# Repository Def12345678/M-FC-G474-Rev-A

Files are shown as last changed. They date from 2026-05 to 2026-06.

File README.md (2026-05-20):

# M-FC — Modular Flight Controller (REV-1)

> **Note:** This is REV-1 — a Proof-of-Concept / educational build. REV-2 is in development and will address known hardware ergonomics issues. Not recommended for production use.

M-FC has been flying on a 5" freestyle build for over a year.

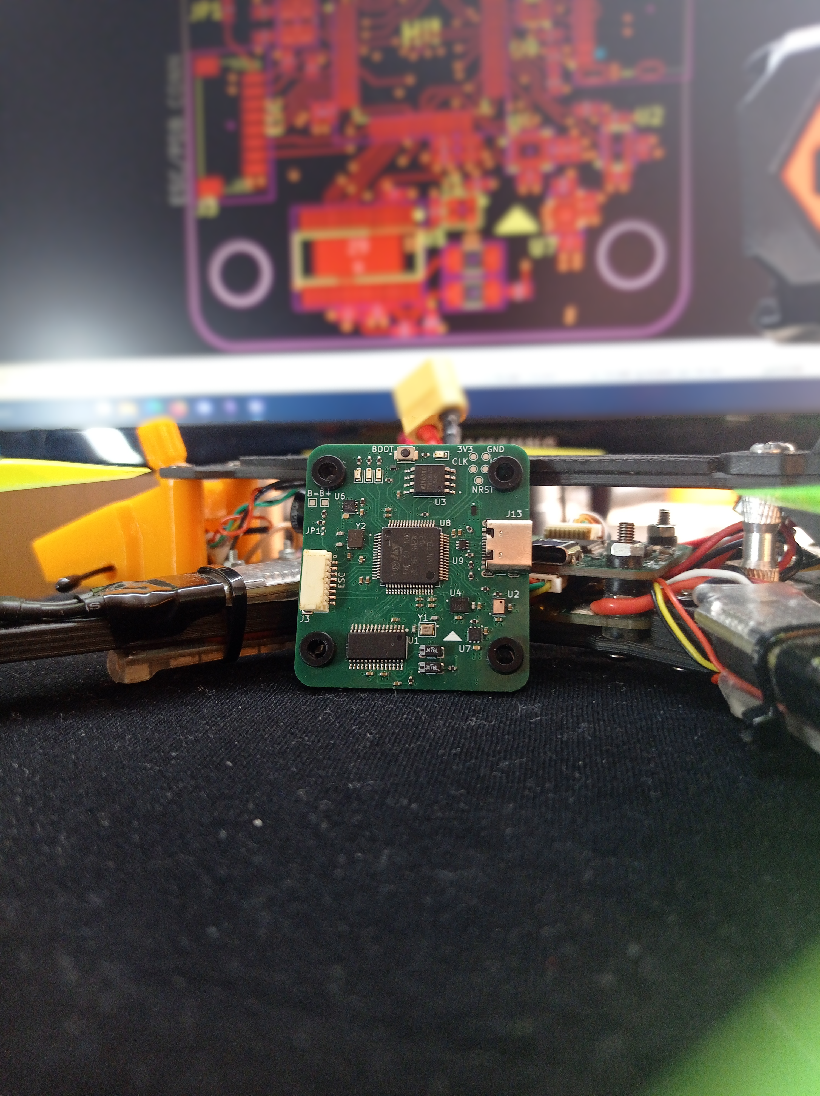
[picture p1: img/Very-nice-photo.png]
M-FC + M-PDB stack installed in Geprc MK4 5" frame


---

## Overview

M-FC is a DIY flight controller designed for FPV drones 30.5x30.5mm mounting holes, built around the STM32G474RET6 microcontroller and running Betaflight 4.6. The "Modular" name reflects the connector philosophy — every peripheral interface is broken out via JST-SH connectors, making wiring clean, repeatable, and swap-friendly.

The board is paired with a dedicated PDB in a standard FC/PDB stack configuration. The FC itself operates at 5V (no onboard BEC), sourcing power from the ESC or PDB. REV-2 will include an onboard BEC.

---

## Hardware Specifications

| Component | Details |
|---|---|
| **MCU** | STM32G474RET6 |
| **IMU** | ICM-42688-P (SPI2) |
| **Barometer** | DPS368 (I2C4) |
| **Magnetometer** | Not populated |
| **OSD** | AT7456E (SPI1) |
| **Blackbox Flash** | W25Q128JVSIQ — 16 MB (SPI3) |
| **USB** | USB-C (with detect on PA10) |
| **Mounting** | 30.5 × 30.5 mm |
| **Input Voltage** | 5V (no onboard BEC — requires 5V from ESC or PDB) |

### Power Architecture

The FC does not regulate voltage from the battery. **5V must be supplied externally** — either from an ESC BEC or from the PDB — via the dedicated 5V pads on the board.

Two separate LDO regulators are present onboard:
- One for the MCU
- One for sensors (IMU, barometer)

A **Schottky diode** is used to isolate USB power from battery power. When powered via USB only, the FC supplies power exclusively to the MCU, sensors (IMU, barometer), OSD chip, flash, GPS, and RX. All remaining peripherals (motors, VTX, etc.) are only powered when the battery is connected via the PDB.

### PDB (Stack)

| Parameter | Value |
|---|---|
| **Max continuous current** | ~120 A total |
| **Per-motor channel** | ~30 A |
| **Configuration** | FC + PDB stack |

The FC connects to the PDB via an 8-pin JST-SH connector plus dedicated `5V_IN` and `GND` solder pads. The `5V_IN` pad powers the FC only — it does not back-feed to the PDB rail.

The PDB includes:
- **5V buck converter** — 2.5 A output
- **9V buck converter** — 2.5 A output (configurable to 12V by replacing resistor R5 — refer to the schematic for the correct resistor value via the linked Texas Instruments buck calculator)

Each ESC must be connected through the PDB. The `VBAT` pin on the 8-pin JST-SH outputs a voltage-divided signal safe for the MCU ADC, used for battery voltage monitoring in Betaflight.

---

## Connector Pinout

All peripheral connections use JST-SH connectors.

| Connector | Pins | Interface | Notes |
|---|---|---|---|
| **ESC** | 8 | DSHOT + telemetry | Motors 1–4 |
| **RX** | 4 | UART | RC receiver |
| **CAM** | 3 | Camera control | Analog camera |
| **VTX** | 4 | UART | Video transmitter |
| **GPS** | 6 | UART + I2C | GPS + compass |
| **LED** | 3 | LED strip | Addressable LEDs |

### Additional Exposed Pads

- **5V input pads** — mandatory external 5V supply
- **PWM 1–3** — additional PWM outputs
- **UART breakout** — spare UART pads
- **I2C breakout** — spare I2C pads

### Photos & Pinout Diagrams

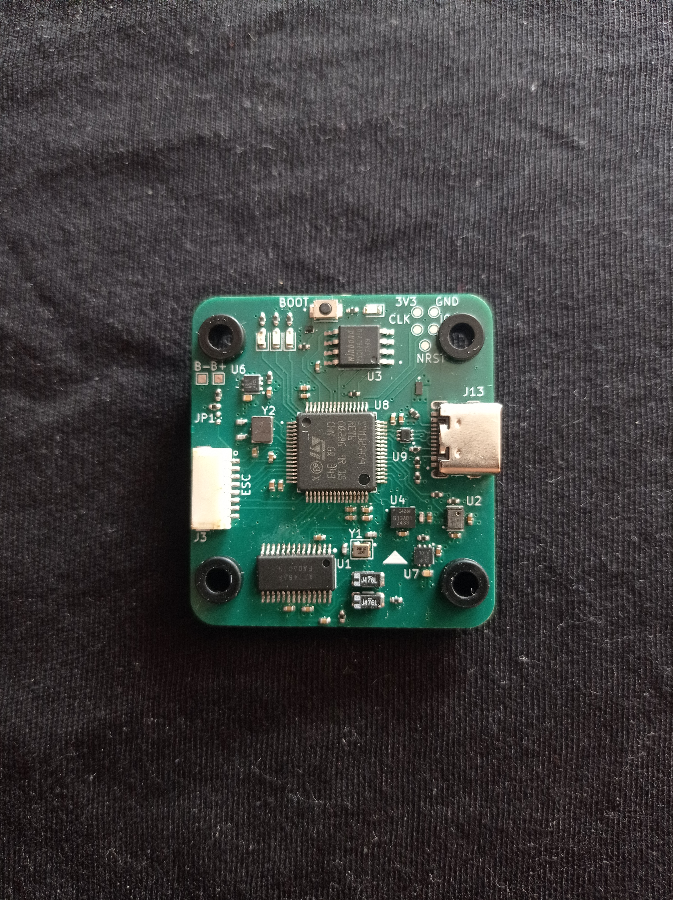
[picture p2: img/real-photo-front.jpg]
M-FC REV-1 — assembled board


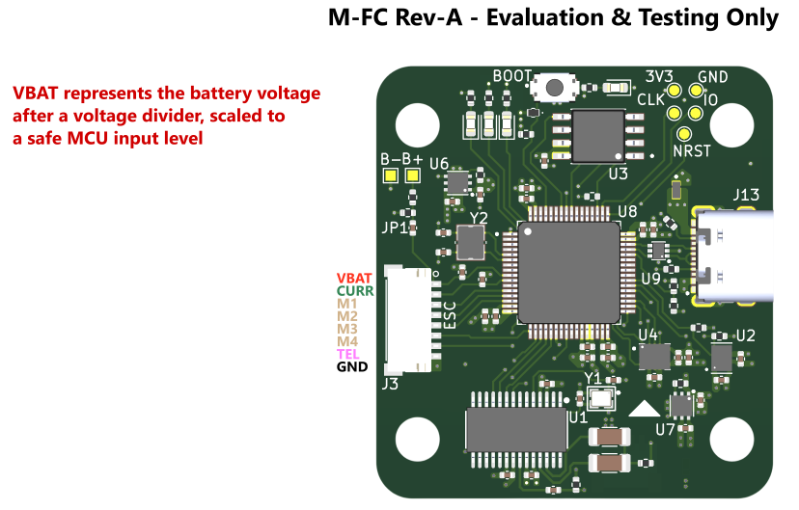
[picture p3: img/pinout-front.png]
Connector pinout — front


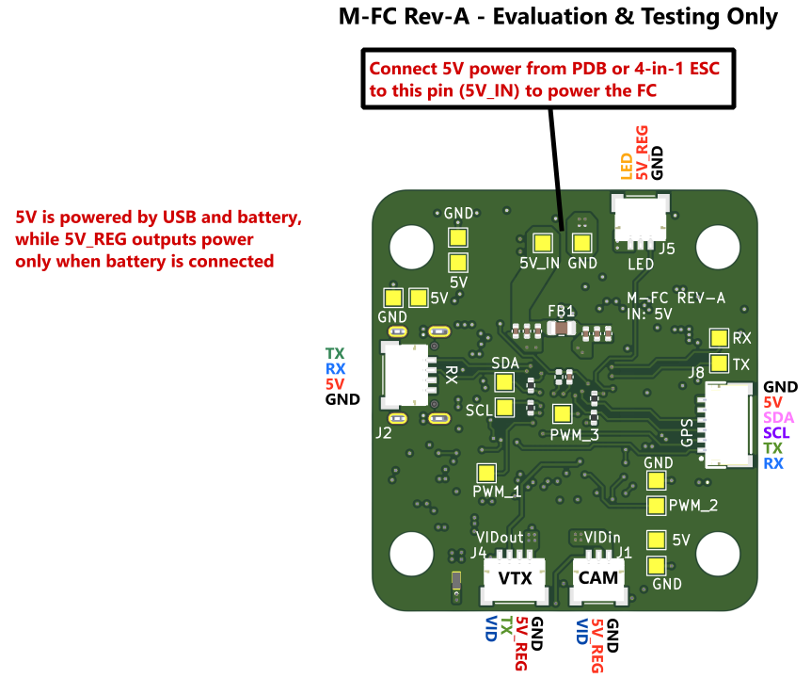
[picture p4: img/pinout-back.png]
Connector pinout — back


Additional renders, routing views, and PCB previews are available in the [`img/`](img/) folder.

---

## Betaflight Target

- **Betaflight version:** 4.6
- **Target name:** `M-FC`
- **MCU family:** `STM32G47X`

Pre-compiled firmware (`.hex`) and the target config file are included in this repository. The hex supports all features listed below.

### Enabled Features

| Feature | Detail |
|---|---|
| Gyroscope / Accelerometer | ICM-42688-P via SPI2 |
| Barometer | DPS368 via I2C4 |
| Blackbox | W25Q128FV via SPI3, default device |
| OSD | MAX7456 (AT7456E) via SPI1 |
| Motors | DSHOT bitbang, pins PA0–PA3 |
| LED strip | PC0 |
| Buzzer | PC3 (inverted) |
| Debug LEDs | PB6, PB7, PB9 |
| VBAT ADC | PC1 |
| Current ADC | PC2 |
| Camera control | PB0 |
| GPS | Enabled |
| Magnetometer | Enabled (I2C2) |
| Position hold | Enabled |
| Altitude hold | Enabled |

### UART Map

| UART | TX | RX | Suggested Use |
|---|---|---|---|
| UART1 | PC4 | PC5 | — |
| UART3 | PB10 | PB11 | — |
| UART4 | PC10 | PC11 | — |
| UART5 | PC12 | PD2 | — |

### I2C Map

| Bus | SCL | SDA | Used for |
|---|---|---|---|
| I2C2 | PA8 | PA9 | Magnetometer |
| I2C3 | PC8 | PC9 | — |
| I2C4 | PC6 | PC7 | Barometer (DPS368) |

### Motor Timer Map

| Index | Pin | Timer | Channel |
|---|---|---|---|
| Motor 1 | PA0 | TIM2 | CH1 |
| Motor 2 | PA1 | TIM2 | CH2 |
| Motor 3 | PA2 | TIM2 | CH3 |
| Motor 4 | PA3 | TIM2 | CH4 |
| CC | PB0 | TIM3 | CH3 |
| LED strip | PC0 | — | CH1 |

---

## Flashing Firmware

### Pre-compiled hex

1. Download the `.hex` file from this repository.
2. Open **Betaflight Configurator 10.10+**.
3. Enter DFU mode — hold the boot button while plugging in USB-C, or send `bl` via CLI.
4. In the **Firmware Flasher** tab, select **Load Firmware [Local]** and pick the `.hex`.
5. Flash. Avoid **Full chip erase** unless necessary.

### Building from source

You can compile your own firmware with custom flags. Copy the target config file into the `configs/` folder of the Betaflight source tree, then build normally.

Building was tested using WSL. Refer to the official Betaflight build guide for setup instructions:
[https://betaflight.com/docs/development/building/Building-in-Ubuntu](https://betaflight.com/docs/development/building/Building-in-Ubuntu)

## Flight Logs & Blackbox Data

Blackbox logs and DVR footage from test flights are available in the [`logs/`](logs/) folder and on https://youtu.be/7Q5jRaf4V_Y(#) / https://pixeldrain.com/u/gxZJVt8E(#).

Logs were recorded using the onboard W25Q128JVSIQ flash via Betaflight 4.6 blackbox at 1kHz.

## Test build
| Component | Details |
|---|---|
| **ESC** | LittleBee Spring 30A (BlueJay firmware) |
| **VTX** | SpeedyBee TX800 (Pagoda2) |
| **RX** | SpeedyBee Nano ELRS |
| **Camera** | Mista 1672 |
| **Motors** | Emax RS2205 2350KV |
| **Battery** | 4S 1550mAh (Ovionic) |
| **Frame** | Geprc MK4 5" |

---

## Known Issues (REV-1)

- **Connector placement ergonomics** — JST-SH connectors are not optimally positioned for clean cable routing in a standard stack build. This is the primary driver for REV-2.
- **Betaflight 4.5 blackbox bug** — Blackbox was unreliable on Betaflight 4.5. Betaflight 4.6 resolves this; use 4.6 or later.
- **No onboard 5V BEC** — Requires external 5V source from ESC or PDB.

---

## Planned Changes (REV-2)

- Revised connector layout for improved cable management
- Onboard 5V BEC
- Additional ergonomic improvements based on REV-1 testing

---

## Acknowledgements

Thanks to [@awocrf](https://github.com/awocrf) for reviewing the schematic for correctness and readability, and for helping with PCB layout aesthetics.

---

## License

This project is released under the **MIT License**. See [LICENSE](LICENSE) for details.

Firmware is based on [Betaflight](https://github.com/betaflight/betaflight), licensed under **GPLv3**.

---

## Contributing

This is currently a personal/educational project. REV-2 is in active development. Issues and suggestions are welcome via GitHub Issues.

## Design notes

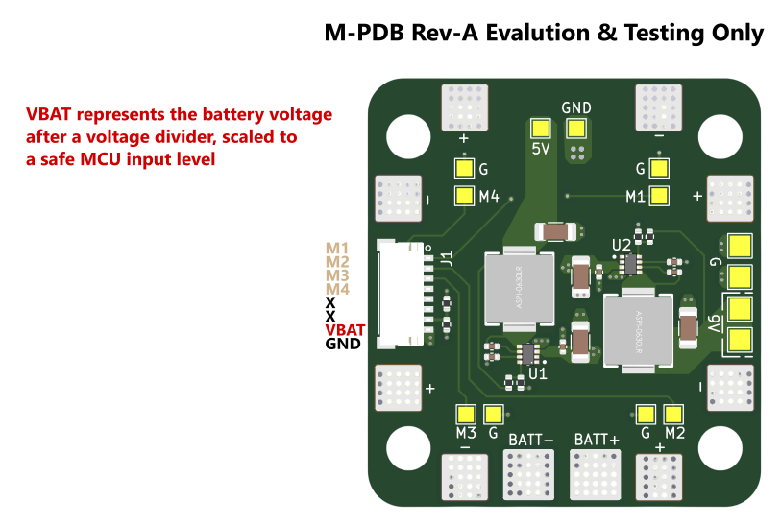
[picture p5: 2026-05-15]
img/M-PDB-img/pinout-M-PDB.png

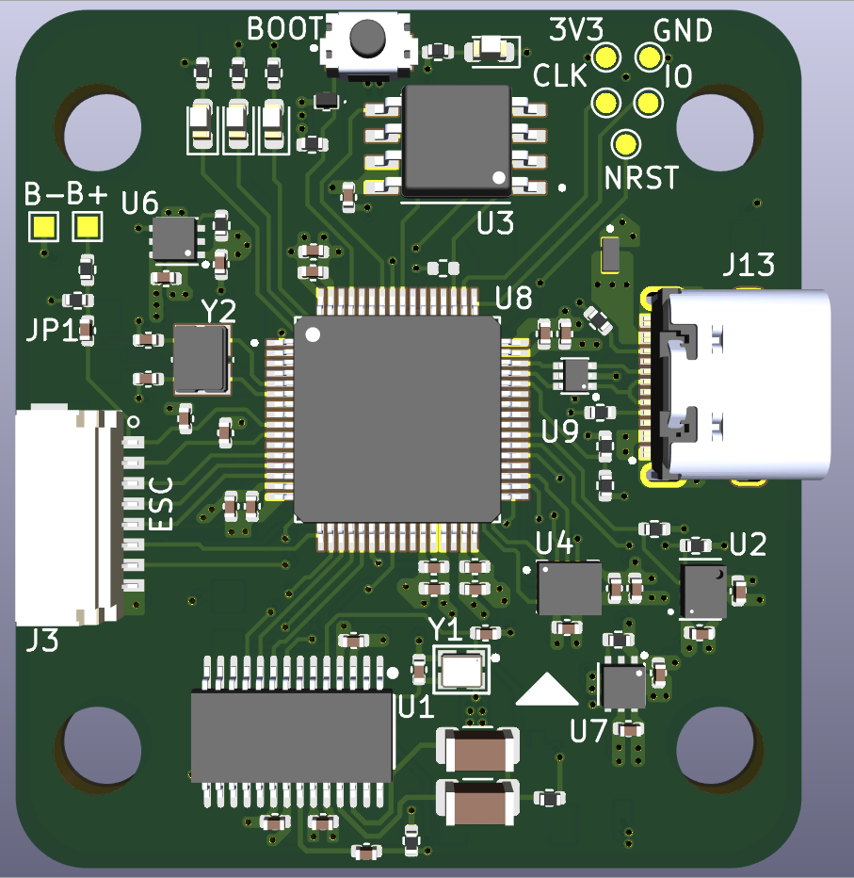
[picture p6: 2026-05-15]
img/render-front.png

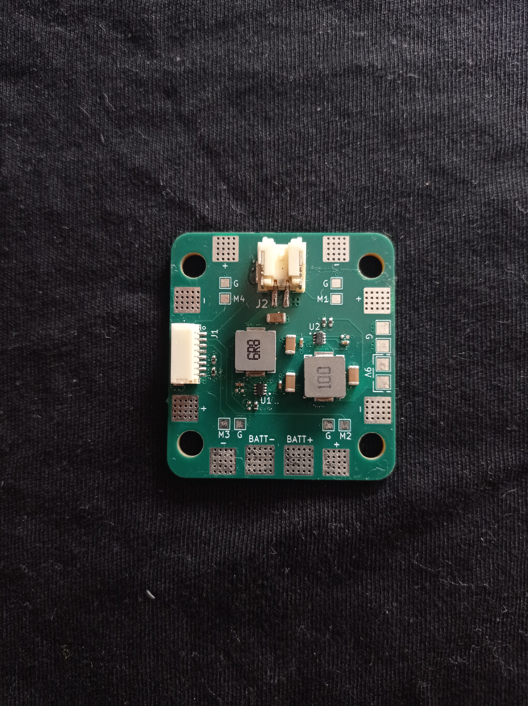
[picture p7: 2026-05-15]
img/M-PDB-img/real-photo-M-PDB.jpg

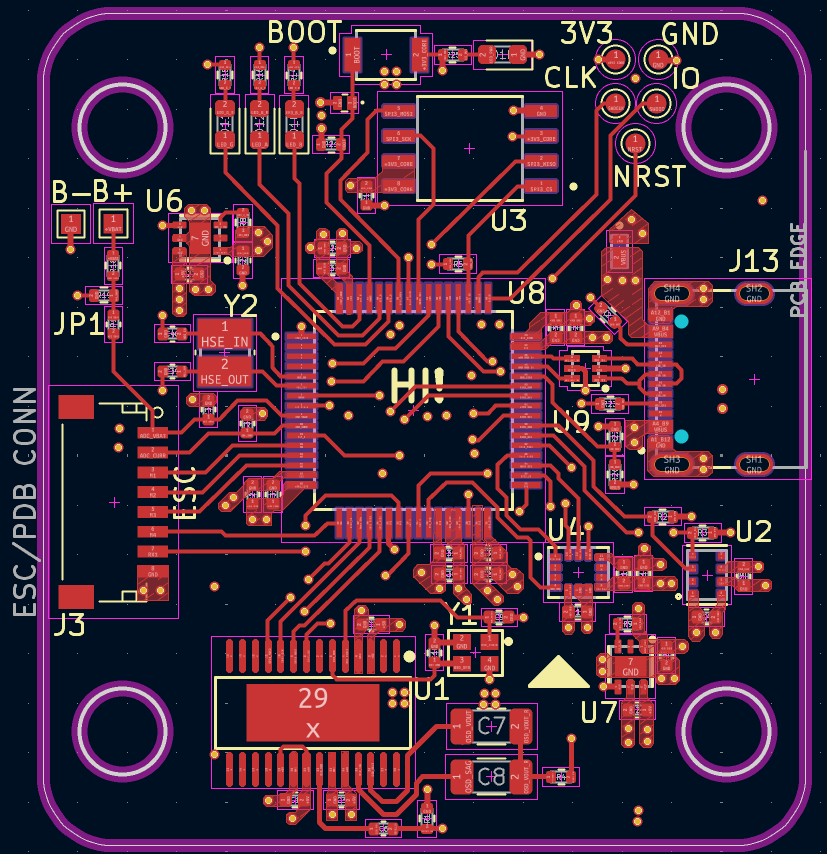
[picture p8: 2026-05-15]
img/routing-first-layer.png

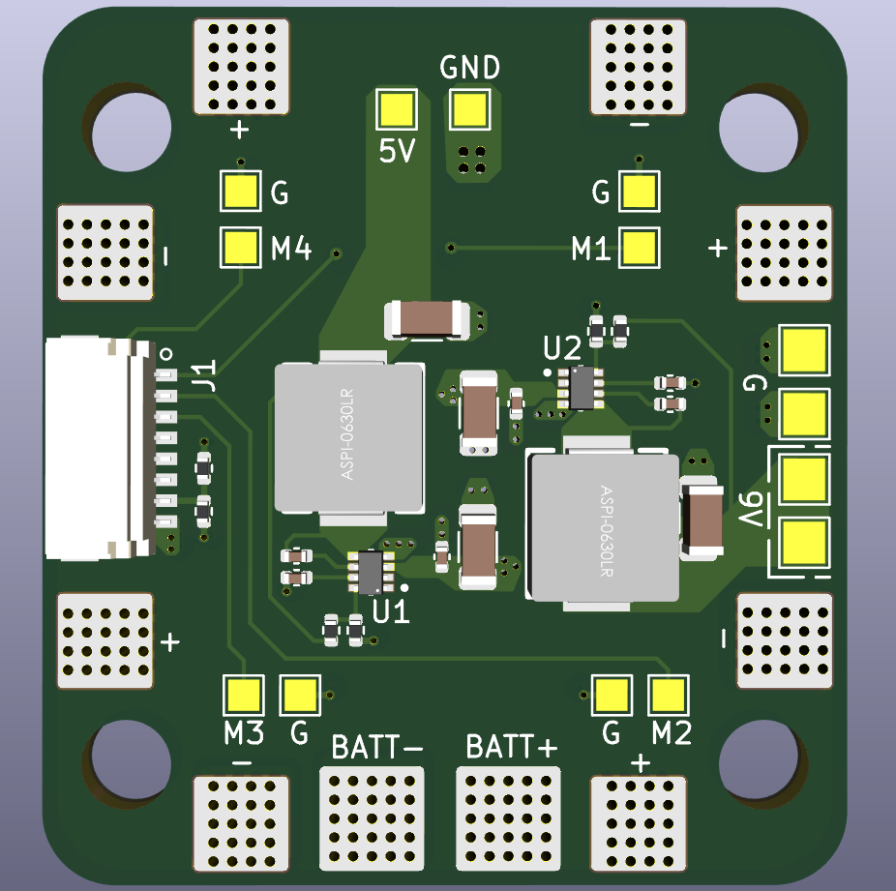
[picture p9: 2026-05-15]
img/M-PDB-img/render-M-PDB.png

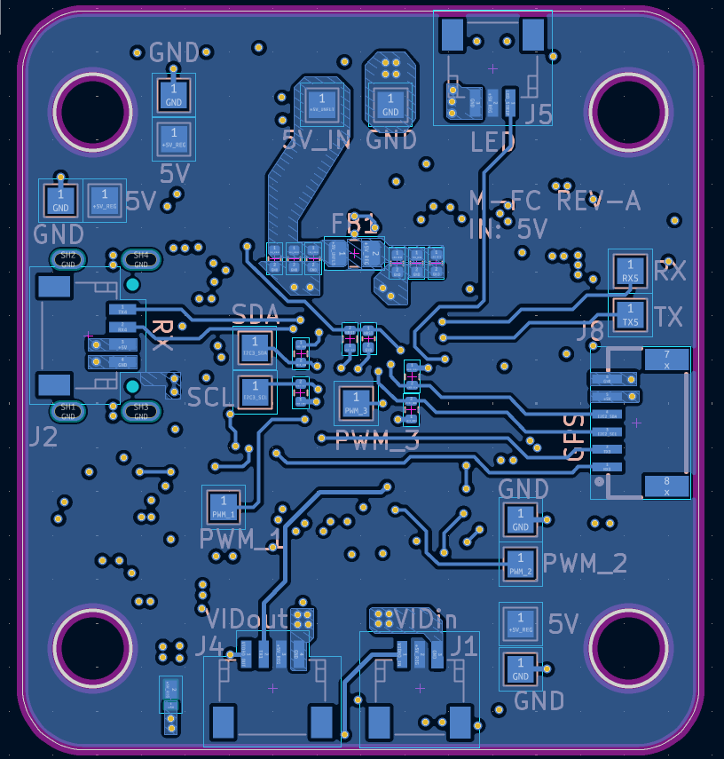
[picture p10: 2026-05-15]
img/routing-fourth-layer.png

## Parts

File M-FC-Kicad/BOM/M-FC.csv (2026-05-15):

Id | Designator | Footprint | Quantity | Designation | Supplier and ref
1 | J3 | JST_SH_SM08B-SRSS-TB_08x1.00mm_Angled | 1 | ESC/PDB CONN
2 | C29,C27,C26,C28,C25,C23 | C_0402_1005Metric | 6 | 1u
3 | C9,C10,C39,C40 | C_0402_1005Metric | 4 | 10p
4 | U7,U6 | SON65P200X200X80-7N | 2 | LP5912-3.3DRV
5 | D18 | LED_0603_1608Metric | 1 | RED
6 | C14,C42,C41 | C_0402_1005Metric | 3 | 10n
7 | C13,C33,C6,C5,C4,C35,C11,C31,C32,C34,C3,C2,C1,C38,C37,C30,C20,C43,C36 | C_0402_1005Metric | 19 | 100n
8 | R16,R15,R25,R14 | R_0402_1005Metric | 4 | 1K
9 | Y1 | CRYSTAL-SMD_4P-L2.0-W1.6-BL | 1 | 27MHz
10 | U2 | XDCR_DPS368XTSA1 | 1 | DPS368XTSA1
11 | U9 | SOT50P160X60-6N | 1 | USBLC6-2P6
12 | R4,R1 | R_0402_1005Metric | 2 | 75
13 | C24,C22,C19,C44 | C_0402_1005Metric | 4 | 10u
14 | R3,R21,R2,R9,R8,R11,R13,R10,R12 | R_0402_1005Metric | 9 | 10k
15 | D10 | LED_0603_1608Metric | 1 | Blue
16 | D11 | LED_0603_1608Metric | 1 | Green
17 | U1 | TSSOP-28_L9.7-W4.4-P0.65-LS6.4-BL-EP-2 | 1 | AT7456E
18 | U3 | SOIC127P790X216-8N | 1 | W25Q128JVSIQ
19 | C12 | C_0402_1005Metric | 1 | 2p2
20 | D2,D1 | DIO_SDM2U40CSP-7B | 2 | SDM2U30CSP-7B
21 | R18,R22,R20 | R_0402_1005Metric | 3 | 100K
22 | R23,R24 | R_0402_1005Metric | 2 | 5K1
23 | C8,C7 | C_1206_3216Metric | 2 | 47u
24 | Y2 | XTAL_NX3225GD-8MHZ-STD-CRA-3 | 1 | 8MHz
25 | R5,R19,R17 | R_0402_1005Metric | 3 | 10K
26 | U8 | QFP50P1200X1200X160-64N | 1 | STM32G474RET6
27 | D14 | ESDALC6V1-1U2 | 1 | ESD
28 | SW1 | SW_B3U-1000P | 1 | BOOT0
29 | D12 | LED_0603_1608Metric | 1 | Amber
30 | U4 | PQFN50P300X250X97-14N | 1 | ICM-42688-P
31 | J13 | KINGHELM_KH-TYPE-C-16P | 1 | USB-C-16P
32 | J4 | JST_SH_SM04B-SRSS-TB_04x1.00mm_Angled | 1 | VTX
33 | J8 | CONN-SMD_6P-P1.00_XUNPU_WAFER-SH1.0-6PWB | 1 | GPS
34 | J1 | JST_SH_SM03B-SRSS-TB_03x1.00mm_Angled | 1 | CAM
35 | FB1 | C_0805_2012Metric | 1 | 300R
36 | J5 | JST_SH_SM03B-SRSS-TB_03x1.00mm_Angled | 1 | LED
37 | J2 | JST_SH_SM04B-SRSS-TB_04x1.00mm_Angled | 1 | RX

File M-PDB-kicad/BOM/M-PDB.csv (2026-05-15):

Id | Designator | Footprint | Quantity | Designation | Supplier and ref
1 | C2,C9,C7,C4 | C_1206_3216Metric | 4 | 10u
2 | L1 | IND-SMD_L7.0-W6.6 | 1 | 6u8
3 | C8,C3,C1,C6 | C_0402_1005Metric | 4 | 100n
4 | J1 | JST_SH_SM08B-SRSS-TB_08x1.00mm_Angled | 1 | FC Conn
5 | C10,C5 | C_0402_1005Metric | 2 | 33n
6 | R5 | R_0402_1005Metric | 1 | 102K
7 | U2,U1 | SOTFL50P160X60-8N | 2 | TPS62933DRLR
8 | L2 | IND-SMD_L7.0-W6.6 | 1 | 10u
9 | R3,R4,R6 | R_0402_1005Metric | 3 | 10K
10 | R1 | R_0402_1005Metric | 1 | 100K
11 | R2 | R_0402_1005Metric | 1 | 52K3

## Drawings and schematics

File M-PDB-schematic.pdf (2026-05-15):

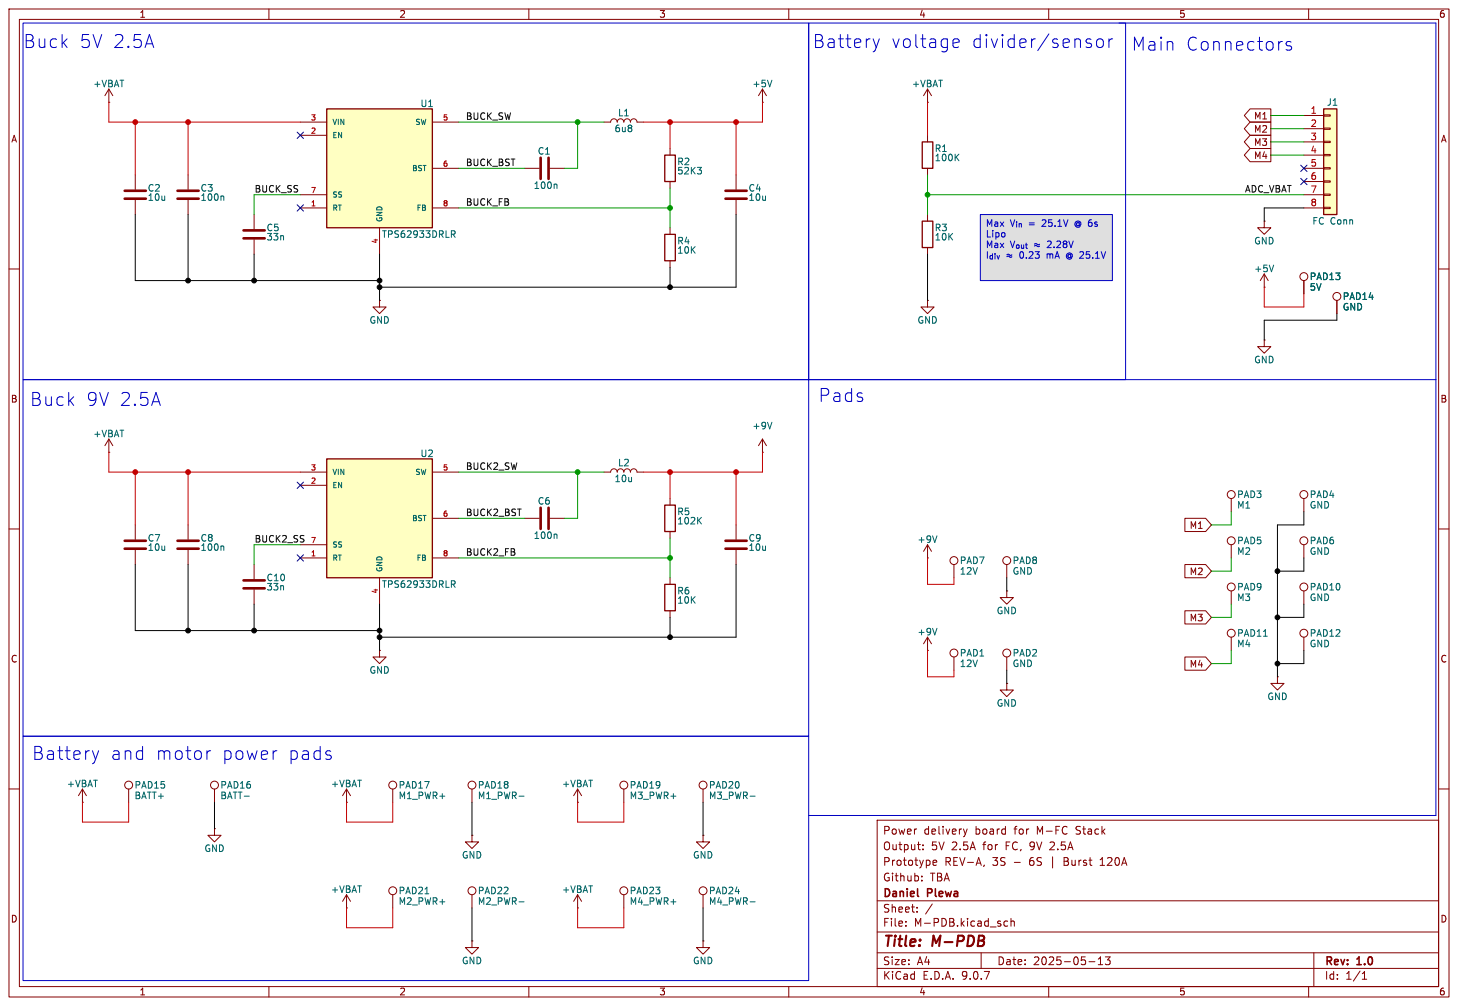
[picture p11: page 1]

Max V_{in}= 25.1V @ 6s Lipo Max V_{out}þÿ"H2.28V

4 SW 5 BST 6 FB 8 U2 TPS62933DRLR GND

Battery and motor power pads

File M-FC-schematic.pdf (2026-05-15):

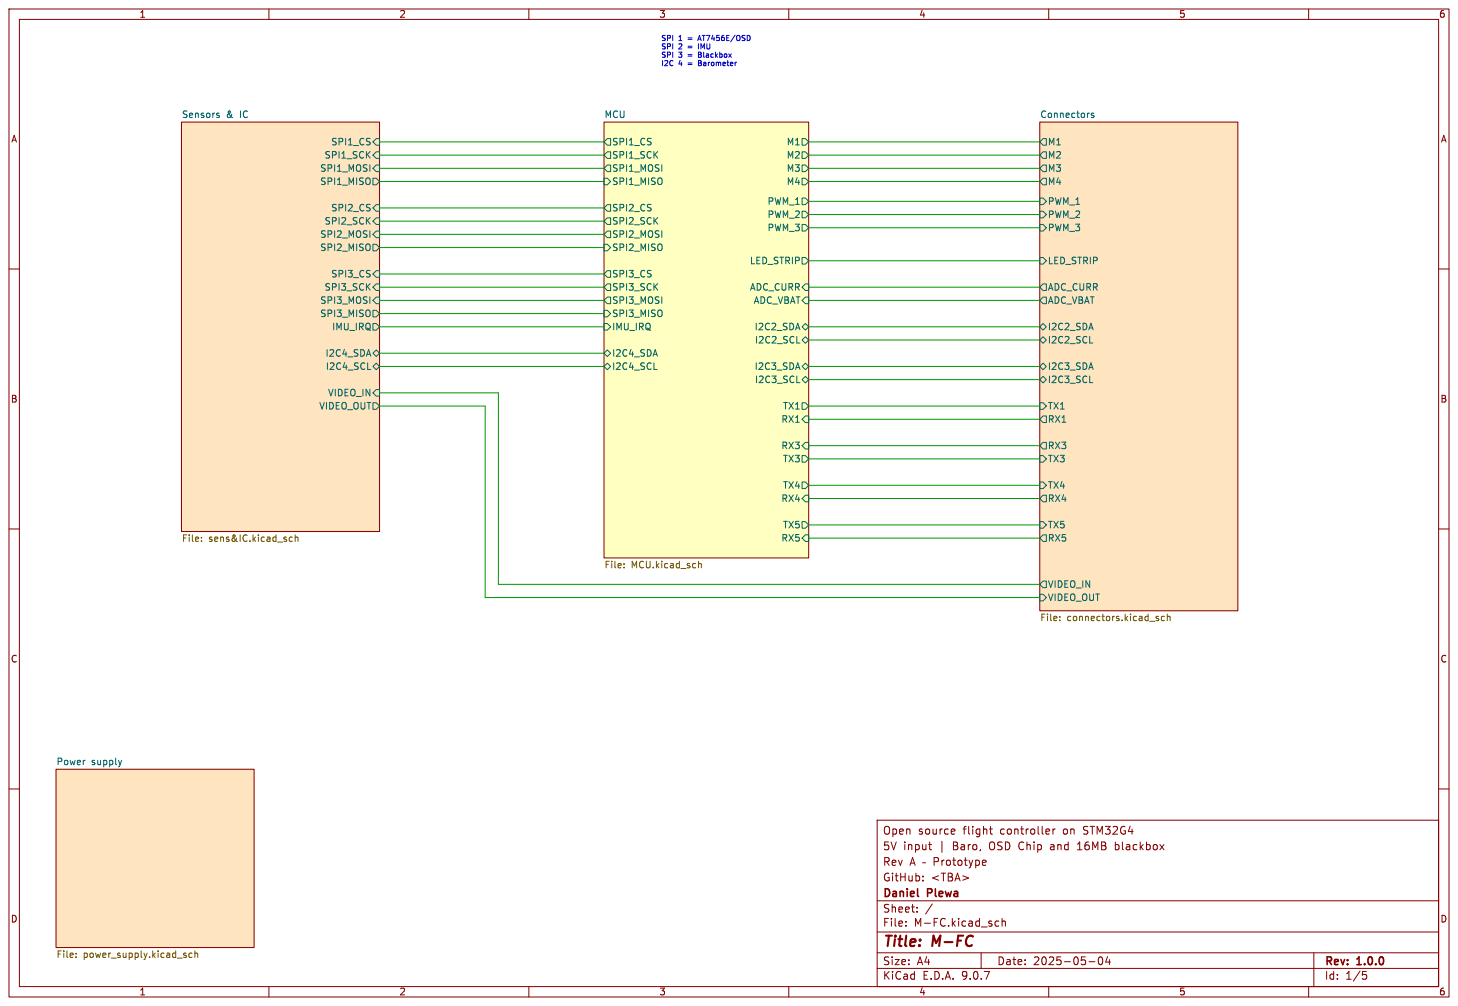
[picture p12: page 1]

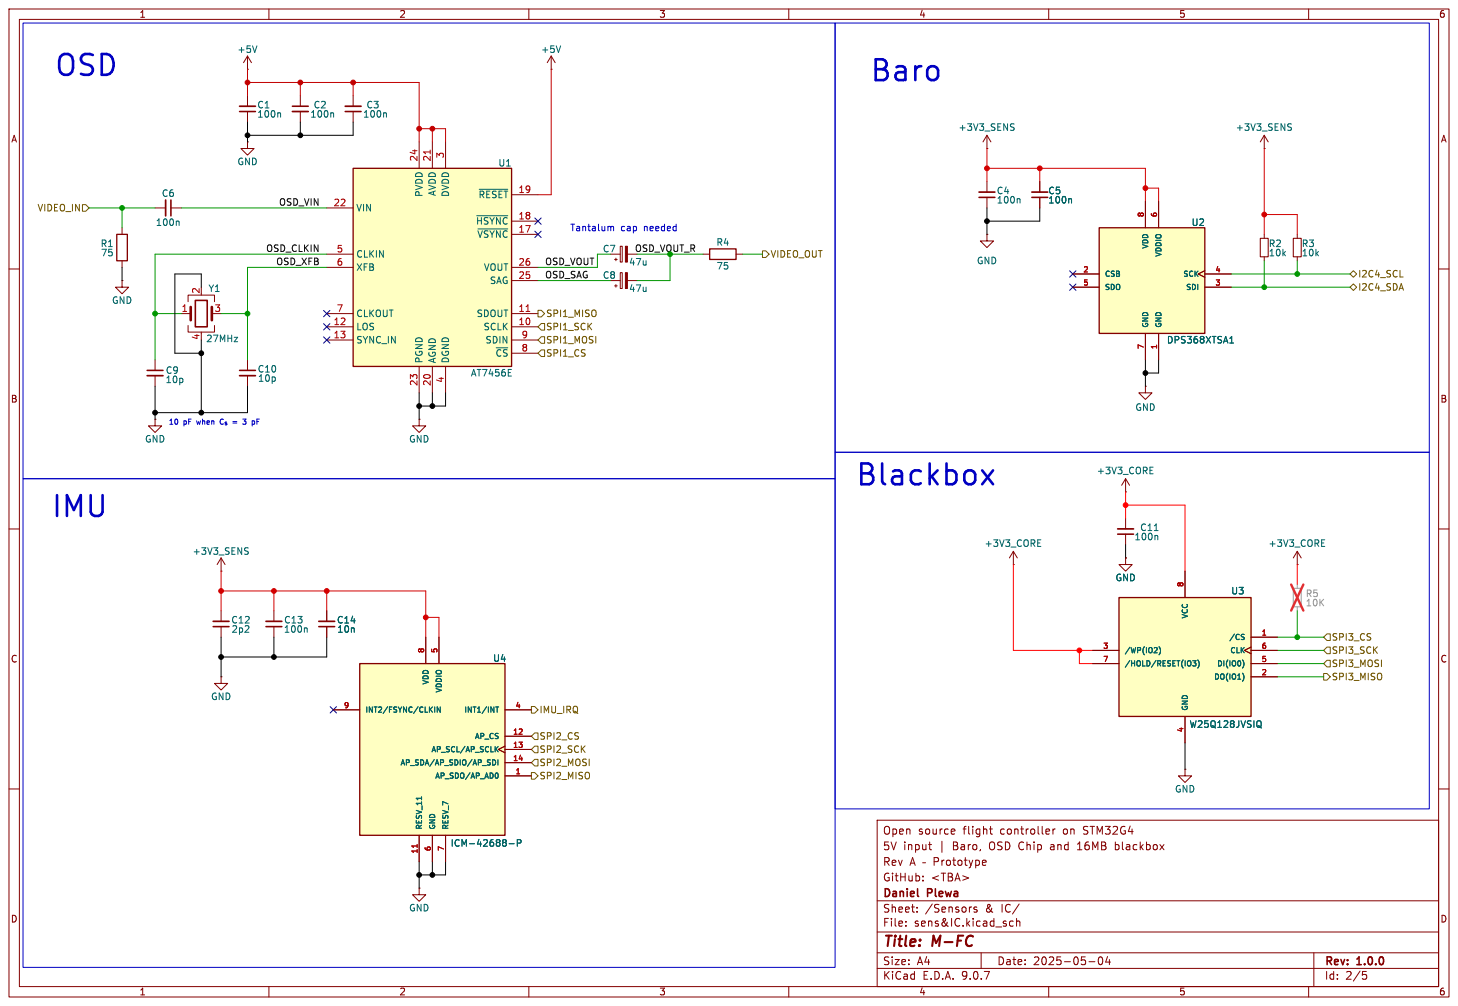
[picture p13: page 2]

4 ~{RESET}19 ~{HSYNC}18 ~{VSYNC}17 VOUT 26 SAG 25 SDOUT 11 SCLK 10 SDIN 9 ~{CS} 8 U1 AT7456E GND

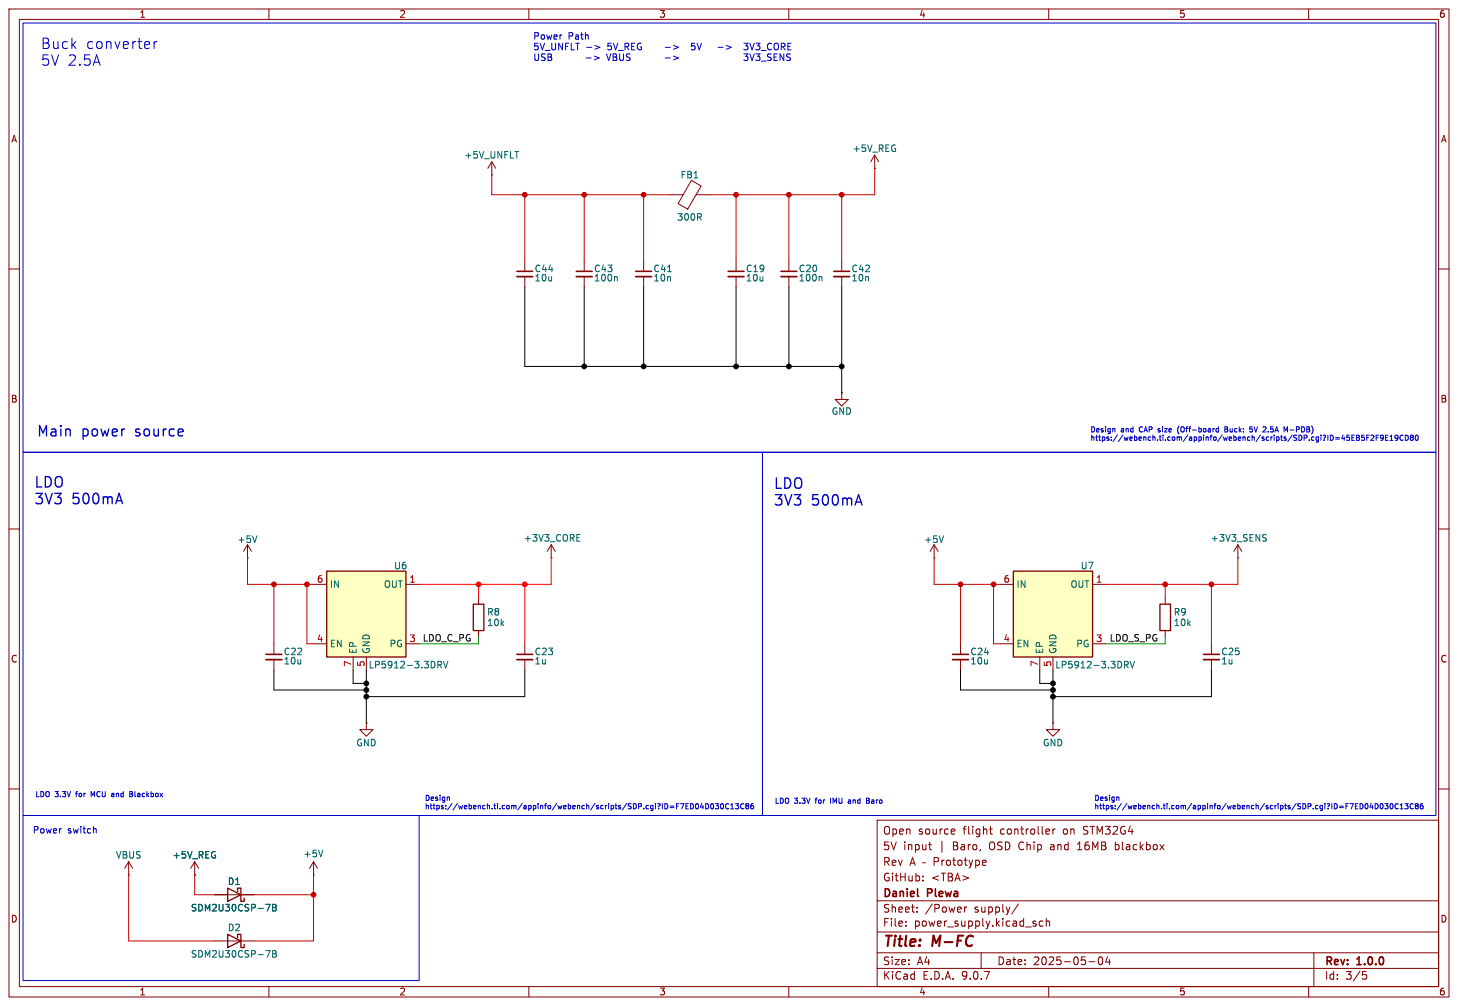
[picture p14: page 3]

LDO 3.3V for MCU and Blackbox Main power source

LDO 3.3V for IMU and Baro LDO

https://webench.ti.com/appinfo/webench/scripts/SDP.cgi?ID=F7ED04D030C13C86

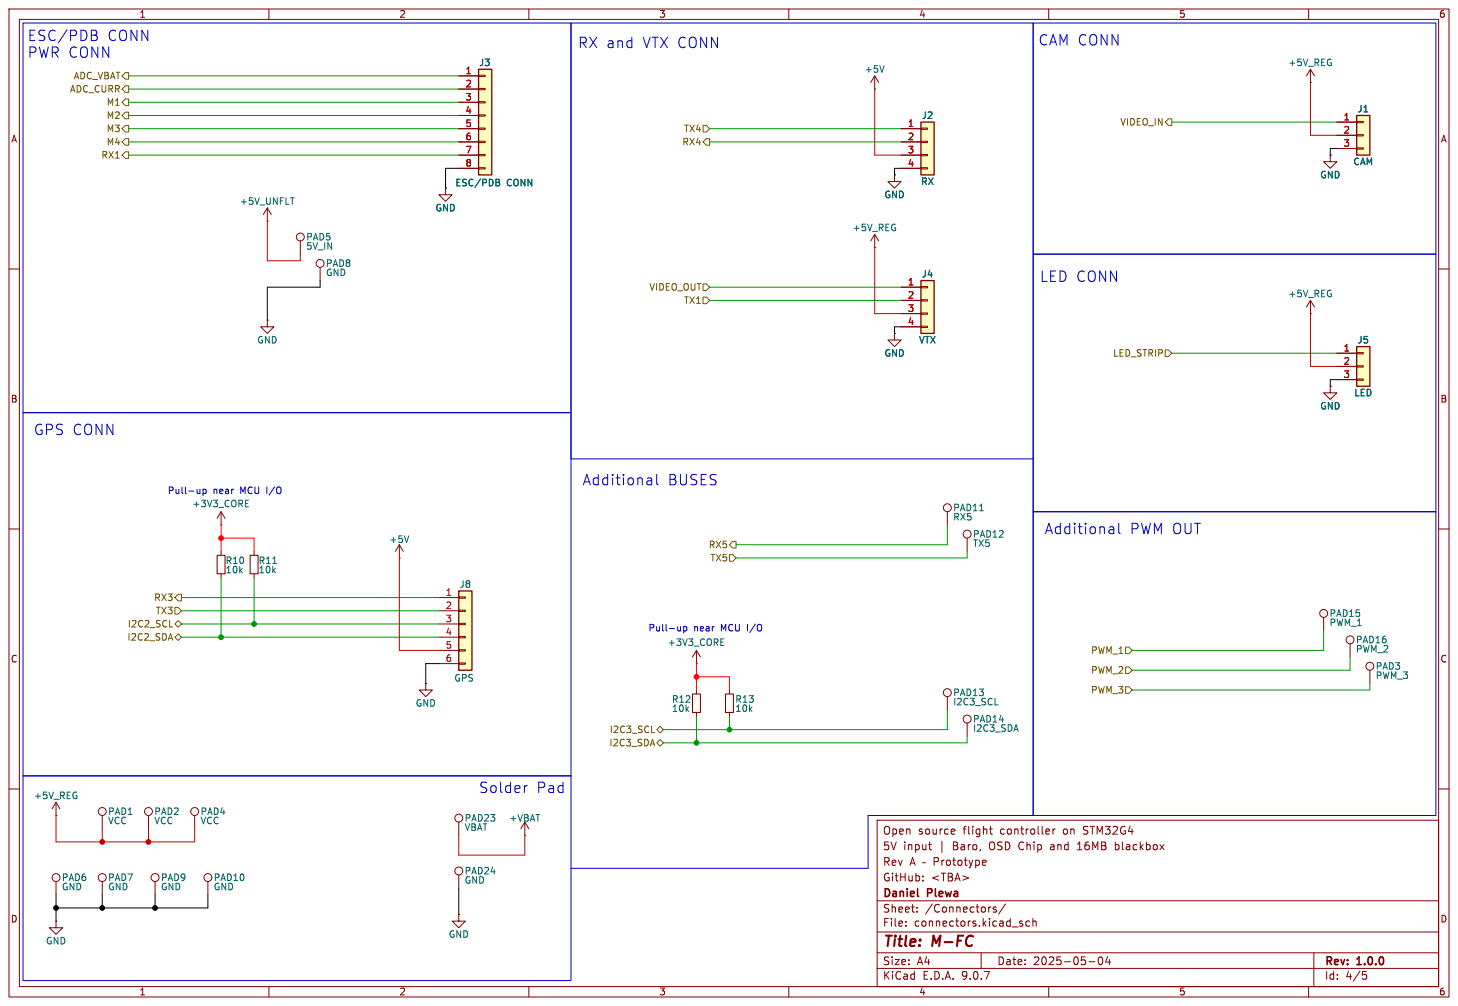
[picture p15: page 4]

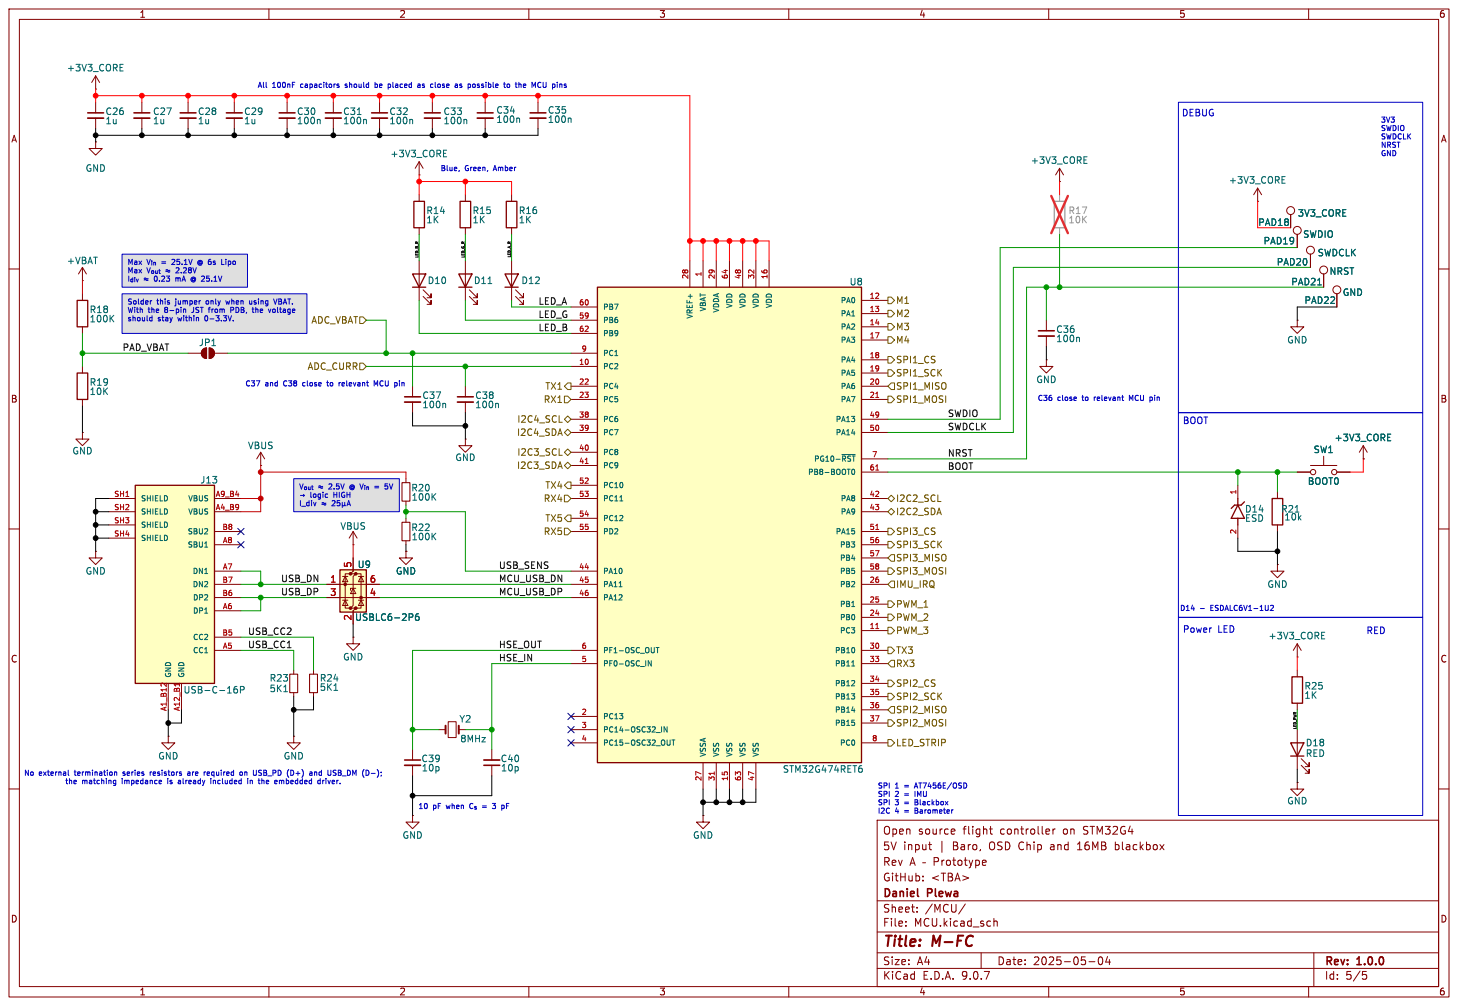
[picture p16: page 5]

SWDCLK NRST GND Power LED

Max V_{in}= 25.1V @ 6s Lipo Max V_{out}þÿ"H2.28V

1 VSSA 27 VDDA 29 VSS 31 VDD 64 VSS 15 VDD 48 VSS 63 VDD 32 VSS 47 VDD 16 PA0 12 PA1 13 PA2 14 PA3 17 PA4 18 PA5 19 PA6 20 PA7 21 PA13 49 PA14 50 PG10-~{RST} 7 PB8-BOOT0 61 PA8 42 PA9 43 PA15 51 PB3 56 PB4 57 PB5 58 PB2 26 PB1 25 PB0 24 PC3 11 PB10 30 PB11 33 PB12 34 PB13 35 PB14 36 PB15 37 PC0 8 U8 STM32G474RET6

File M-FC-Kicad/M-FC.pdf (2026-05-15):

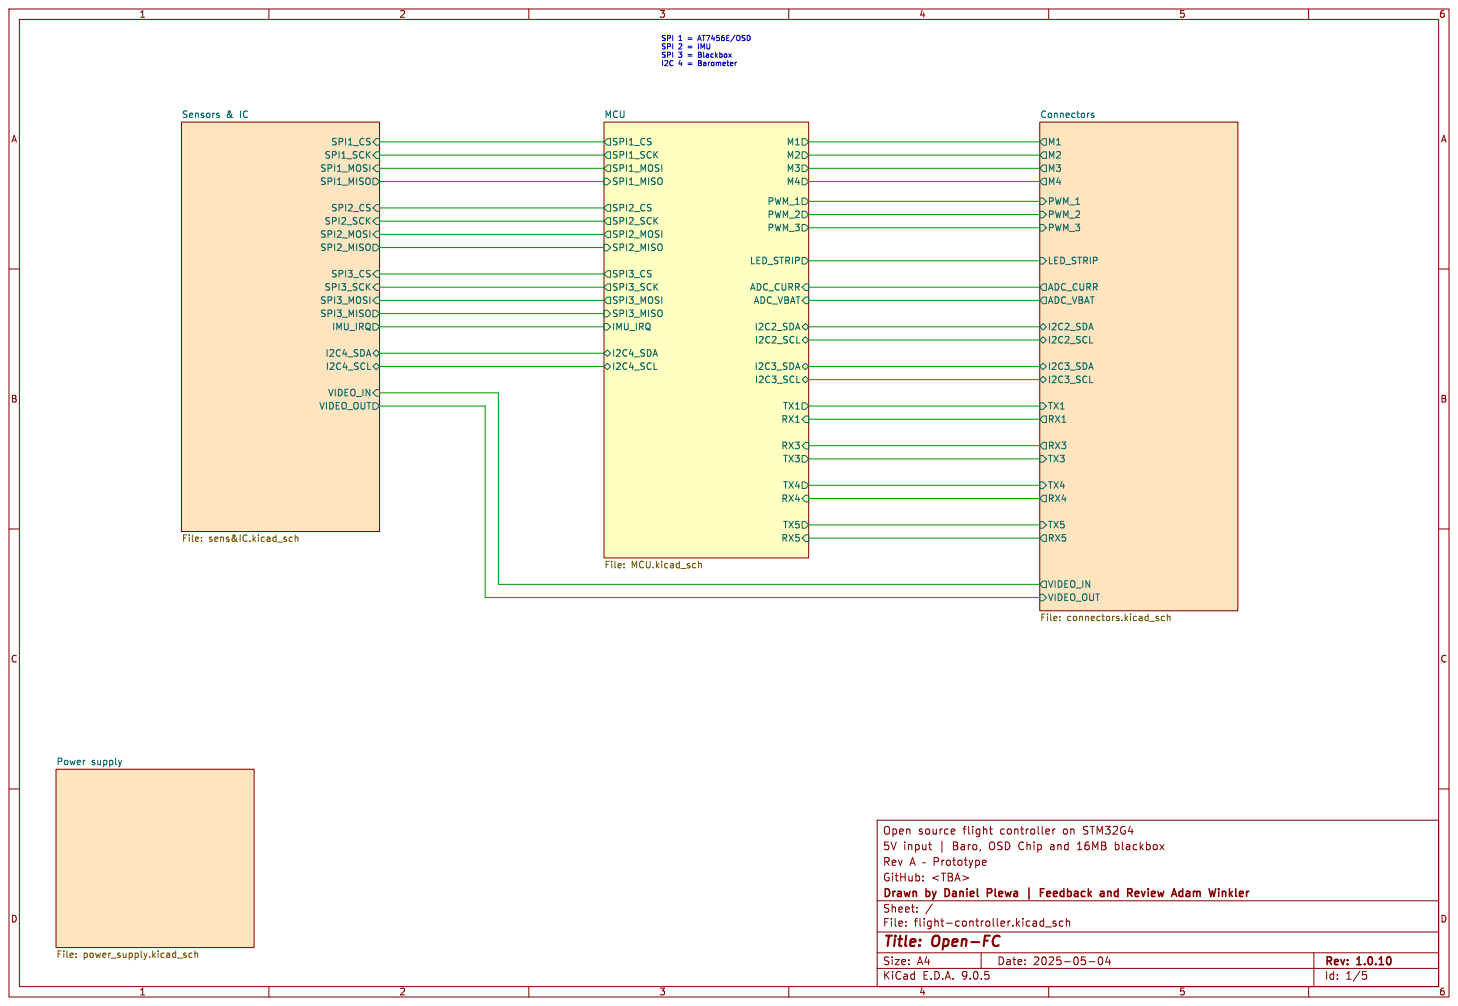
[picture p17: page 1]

Id: 1/5 Title: Open-FC

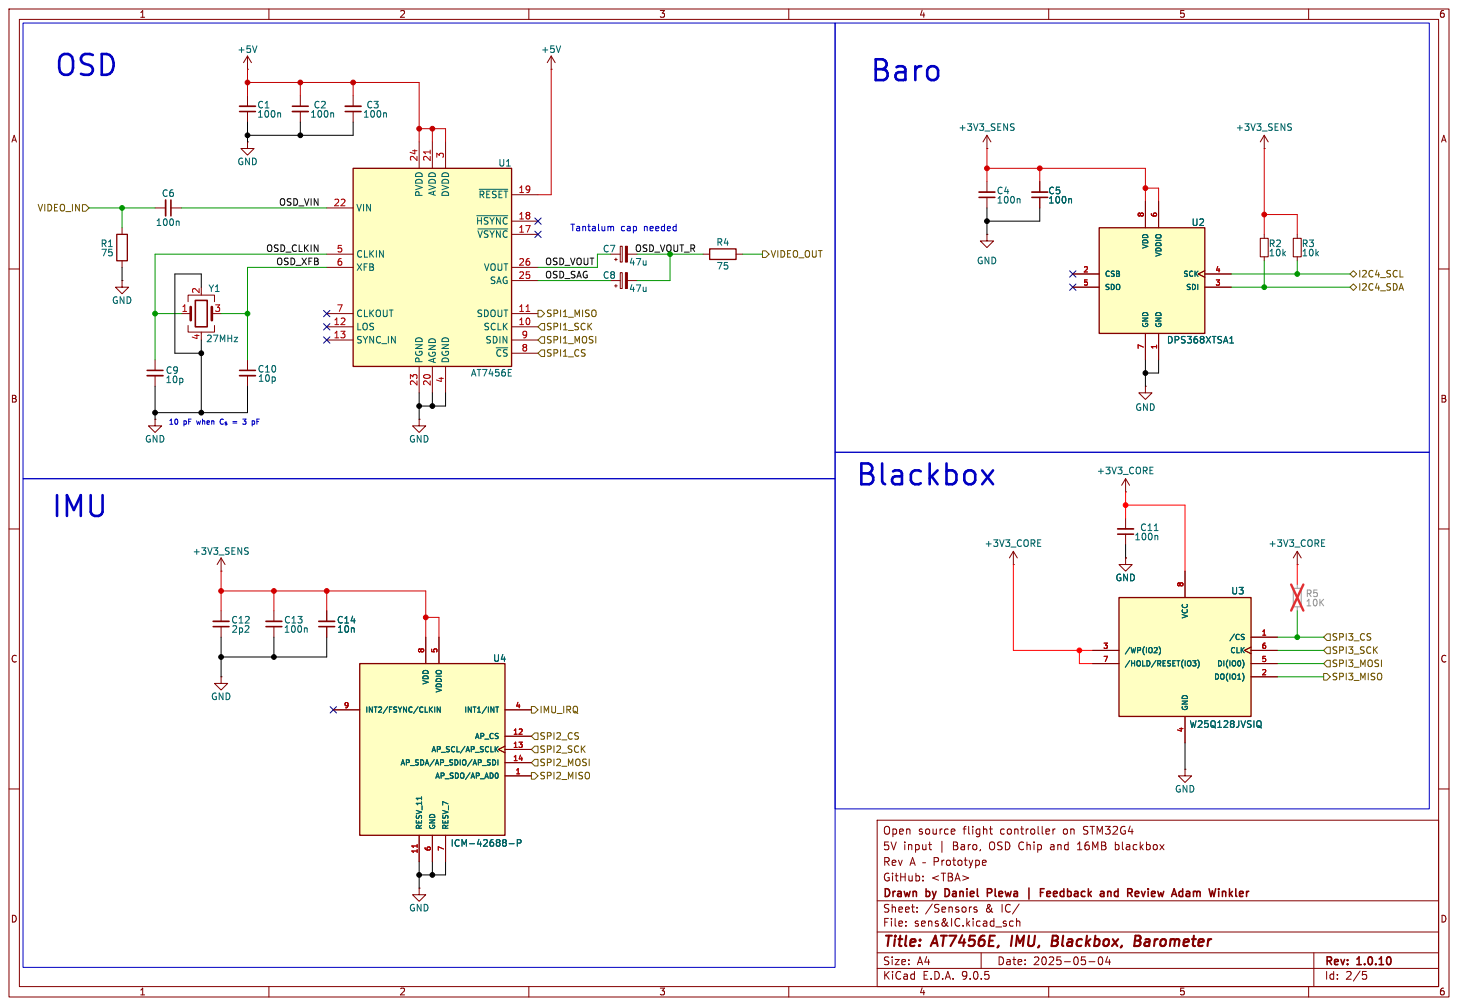
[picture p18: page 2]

4 ~{RESET}19 ~{HSYNC}18 ~{VSYNC}17 VOUT 26 SAG 25 SDOUT 11 SCLK 10 SDIN 9 ~{CS} 8 U1 AT7456E C3

VIDEO_IN
Tantalum cap needed IMU

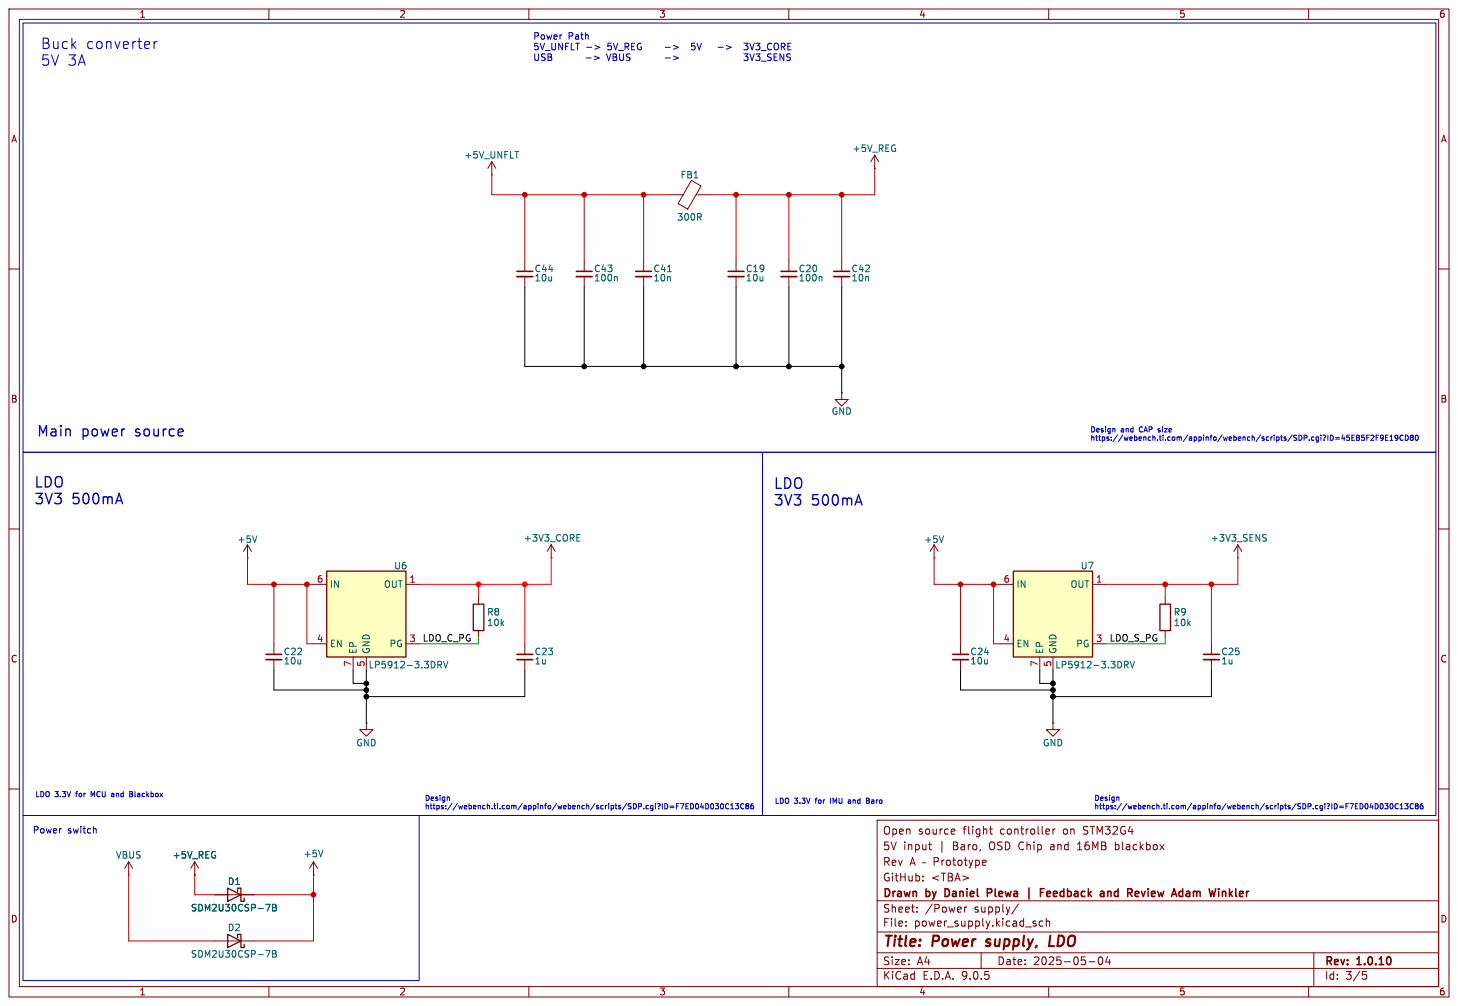
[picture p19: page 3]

LDO 3.3V for MCU and Blackbox Main power source

Design and CAP size
https://webench.ti.com/appinfo/webench/scripts/SDP.cgi?ID=45EB5F2F9E19CD80 Design

LDO 3.3V for IMU and Baro LDO

https://webench.ti.com/appinfo/webench/scripts/SDP.cgi?ID=F7ED04D030C13C86

Id: 3/5 Title: Power supply, LDO

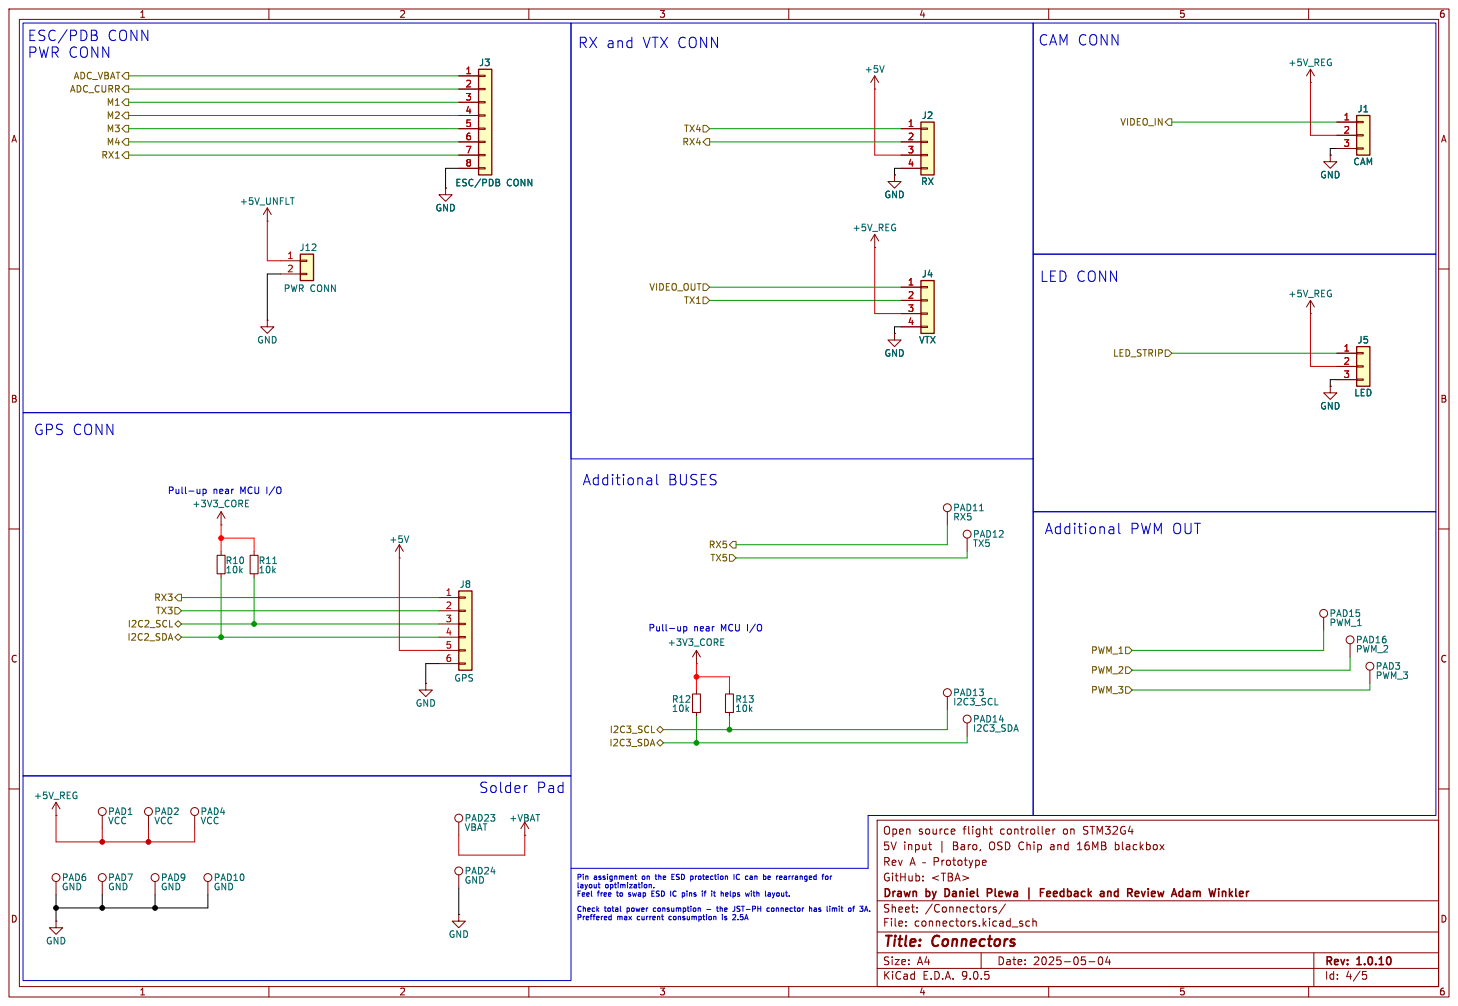
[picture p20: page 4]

RX and VTX CONN ESC/PDB CONN
PWR CONN
I2C2_SCL RX3 TX3 RX1

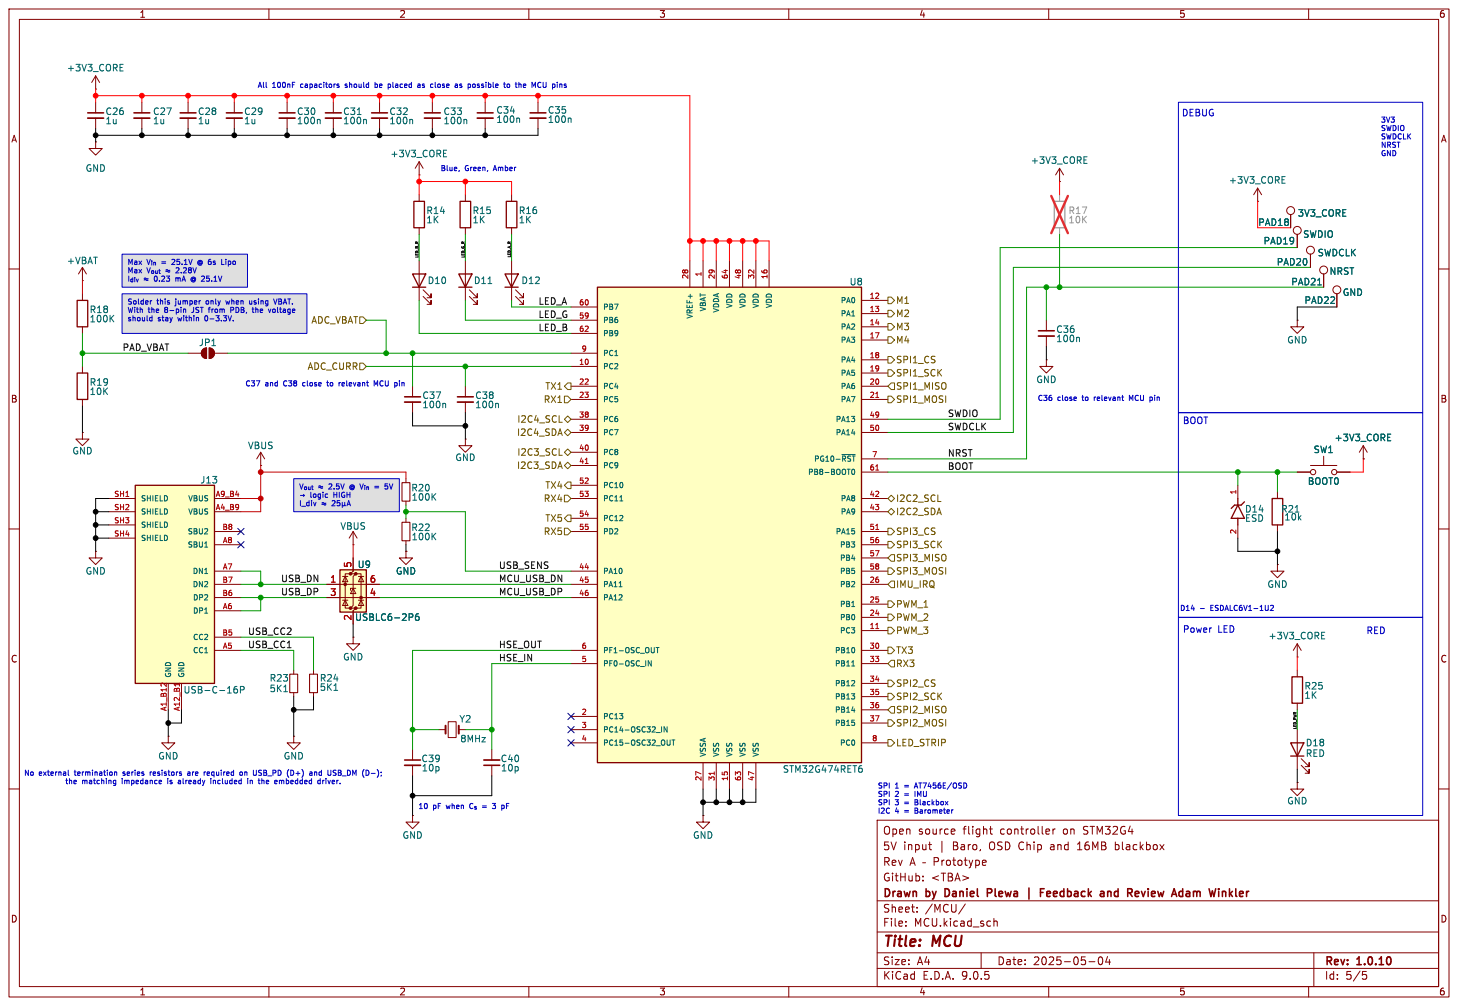
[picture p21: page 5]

SWDCLK NRST GND Power LED

Max V_{in}= 25.1V @ 6s Lipo Max V_{out}þÿ"H2.28V

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

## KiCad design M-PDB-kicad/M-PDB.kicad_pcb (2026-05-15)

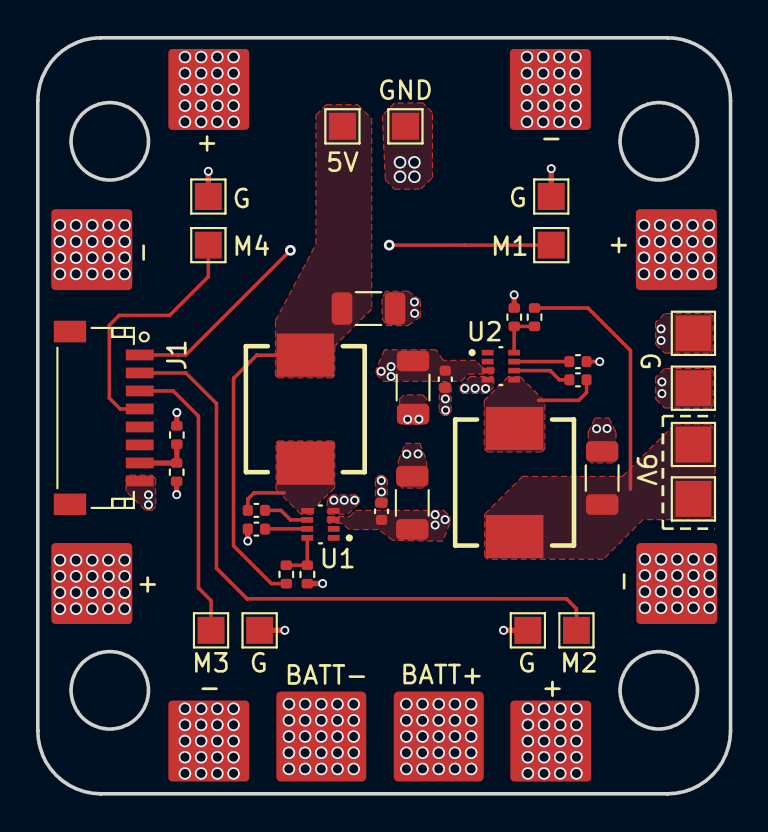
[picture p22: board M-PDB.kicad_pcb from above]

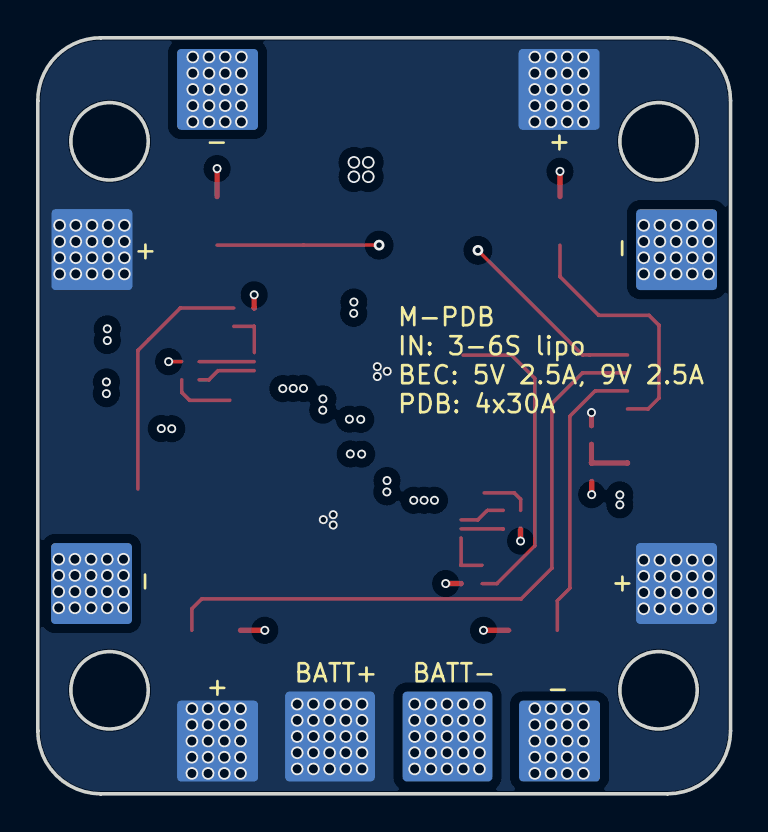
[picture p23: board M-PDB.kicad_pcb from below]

Board: 4 copper layers, 38.5 x 42.0 mm, 55 parts (10 on the bottom side), 17 nets.

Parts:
C1, C3, C6, C8: 100n; C_0402_1005Metric
C2, C4, C7, C9: 10u; C_1206_3216Metric
C5, C10: 33n; C_0402_1005Metric
J1: FC Conn; JST_SH_SM08B-SRSS-TB_08x1.00mm_Angled
L1: 6u8; IND-SMD_L7.0-W6.6
L2: 10u; IND-SMD_L7.0-W6.6
PAD1, PAD7: 12V; TestPoint_Pad_2.0x2.0mm
PAD2, PAD8: GND; TestPoint_Pad_2.0x2.0mm
PAD3: M1; TestPoint_Pad_1.5x1.5mm
PAD4, PAD6, PAD10, PAD12, PAD14: GND; TestPoint_Pad_1.5x1.5mm
PAD5: M2; TestPoint_Pad_1.5x1.5mm
PAD9: M3; TestPoint_Pad_1.5x1.5mm
PAD11: M4; TestPoint_Pad_1.5x1.5mm
PAD13: 5V; TestPoint_Pad_1.5x1.5mm
PAD15, PAD15#2: BATT+; pad5x5
PAD16, PAD16#2: BATT-; pad5x5
PAD17, PAD17#2: M1_PWR+; pad4.5
PAD18, PAD18#2: M1_PWR-; pad4.5
PAD19, PAD19#2: M3_PWR+; pad4.5
PAD20, PAD20#2: M3_PWR-; pad4.5
PAD21, PAD21#2: M2_PWR+; pad4.5
PAD22, PAD22#2: M2_PWR-; pad4.5
PAD23, PAD23#2: M4_PWR+; pad4.5
PAD24, PAD24#2: M4_PWR-; pad4.5
R1: 100K; R_0402_1005Metric
R2: 52K3; R_0402_1005Metric
R3, R4, R6: 10K; R_0402_1005Metric
R5: 102K; R_0402_1005Metric
U1, U2: TPS62933DRLR; SOTFL50P160X60-8N

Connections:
+5V: C4.1, L1.2, PAD13.1, R2.1
+9V: C9.1, L2.2, PAD1.1, PAD7.1, R5.1
+VBAT: C2.1, C3.1, C7.1, C8.1, PAD15.1, PAD15#2.1, PAD17.1, PAD17#2.1, PAD19.1, PAD19#2.1, PAD21.1, PAD21#2.1, PAD23.1, PAD23#2.1, R1.1, U1.3 (VIN), U2.3 (VIN)
/ADC_VBAT: J1.7, R1.2, R3.1
/BUCK2_BST: C6.1, U2.6 (BST)
/BUCK2_FB: R5.2, R6.1, U2.8 (FB)
/BUCK2_SS: C10.1, U2.7 (SS)
/BUCK2_SW: C6.2, L2.1, U2.5 (SW)
/BUCK_BST: C1.1, U1.6 (BST)
/BUCK_FB: R2.2, R4.1, U1.8 (FB)
/BUCK_SS: C5.1, U1.7 (SS)
/BUCK_SW: C1.2, L1.1, U1.5 (SW)
GND: C2.2, C3.2, C4.2, C5.2, C7.2, C8.2, C9.2, C10.2, J1.8, PAD2.1, PAD4.1, PAD6.1, PAD8.1, PAD10.1, PAD12.1, PAD14.1, PAD16.1, PAD16#2.1, PAD18.1, PAD18#2.1, PAD20.1, PAD20#2.1, PAD22.1, PAD22#2.1, PAD24.1, PAD24#2.1, R3.2, R4.2, R6.2, U1.4 (GND), U2.4 (GND)
M1: J1.1, PAD3.1
M2: J1.2, PAD5.1
M3: J1.3, PAD9.1
M4: J1.4, PAD11.1

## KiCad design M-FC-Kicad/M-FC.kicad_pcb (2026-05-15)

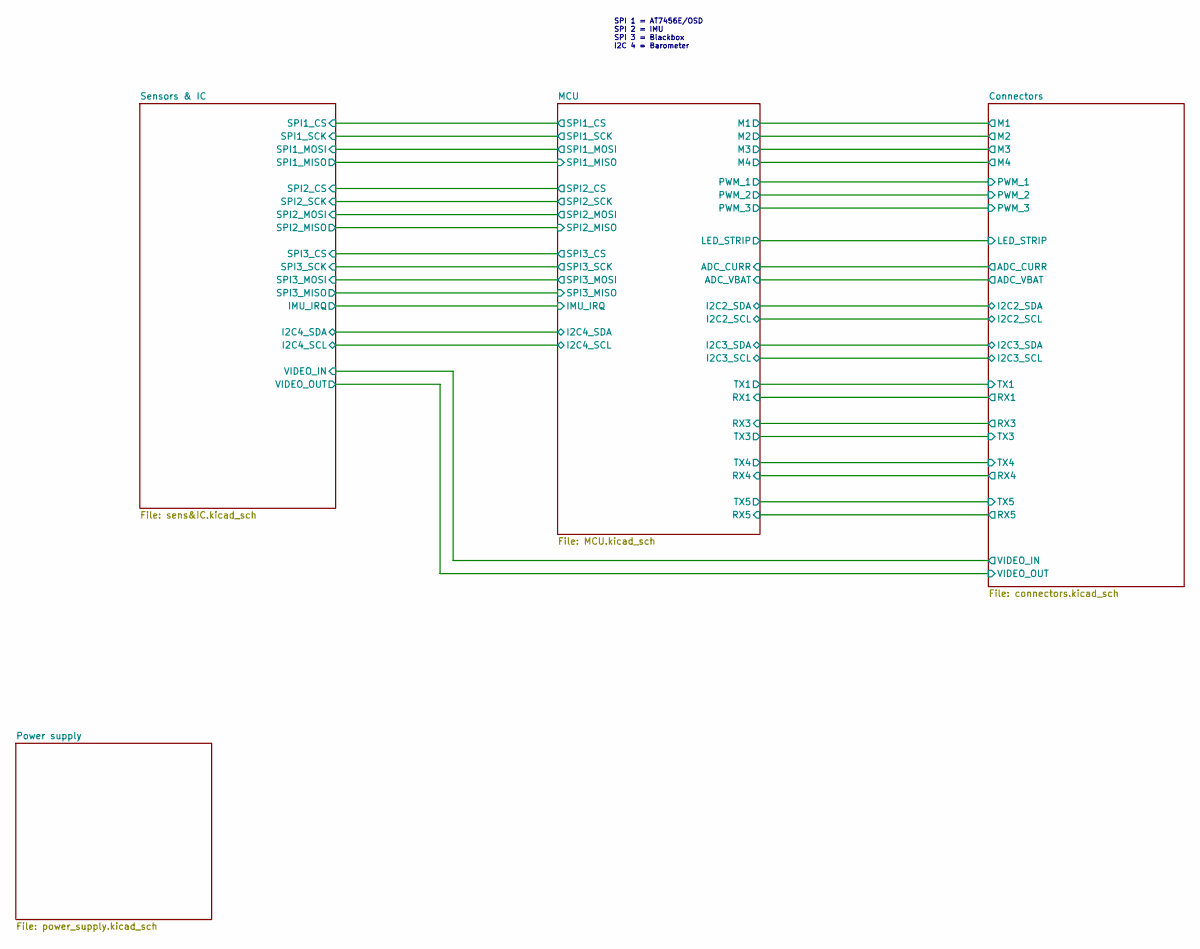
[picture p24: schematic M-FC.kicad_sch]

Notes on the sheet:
SPI 1 = AT7456E/OSD SPI 2 = IMU SPI 3 = Blackbox I2C 4 = Barometer

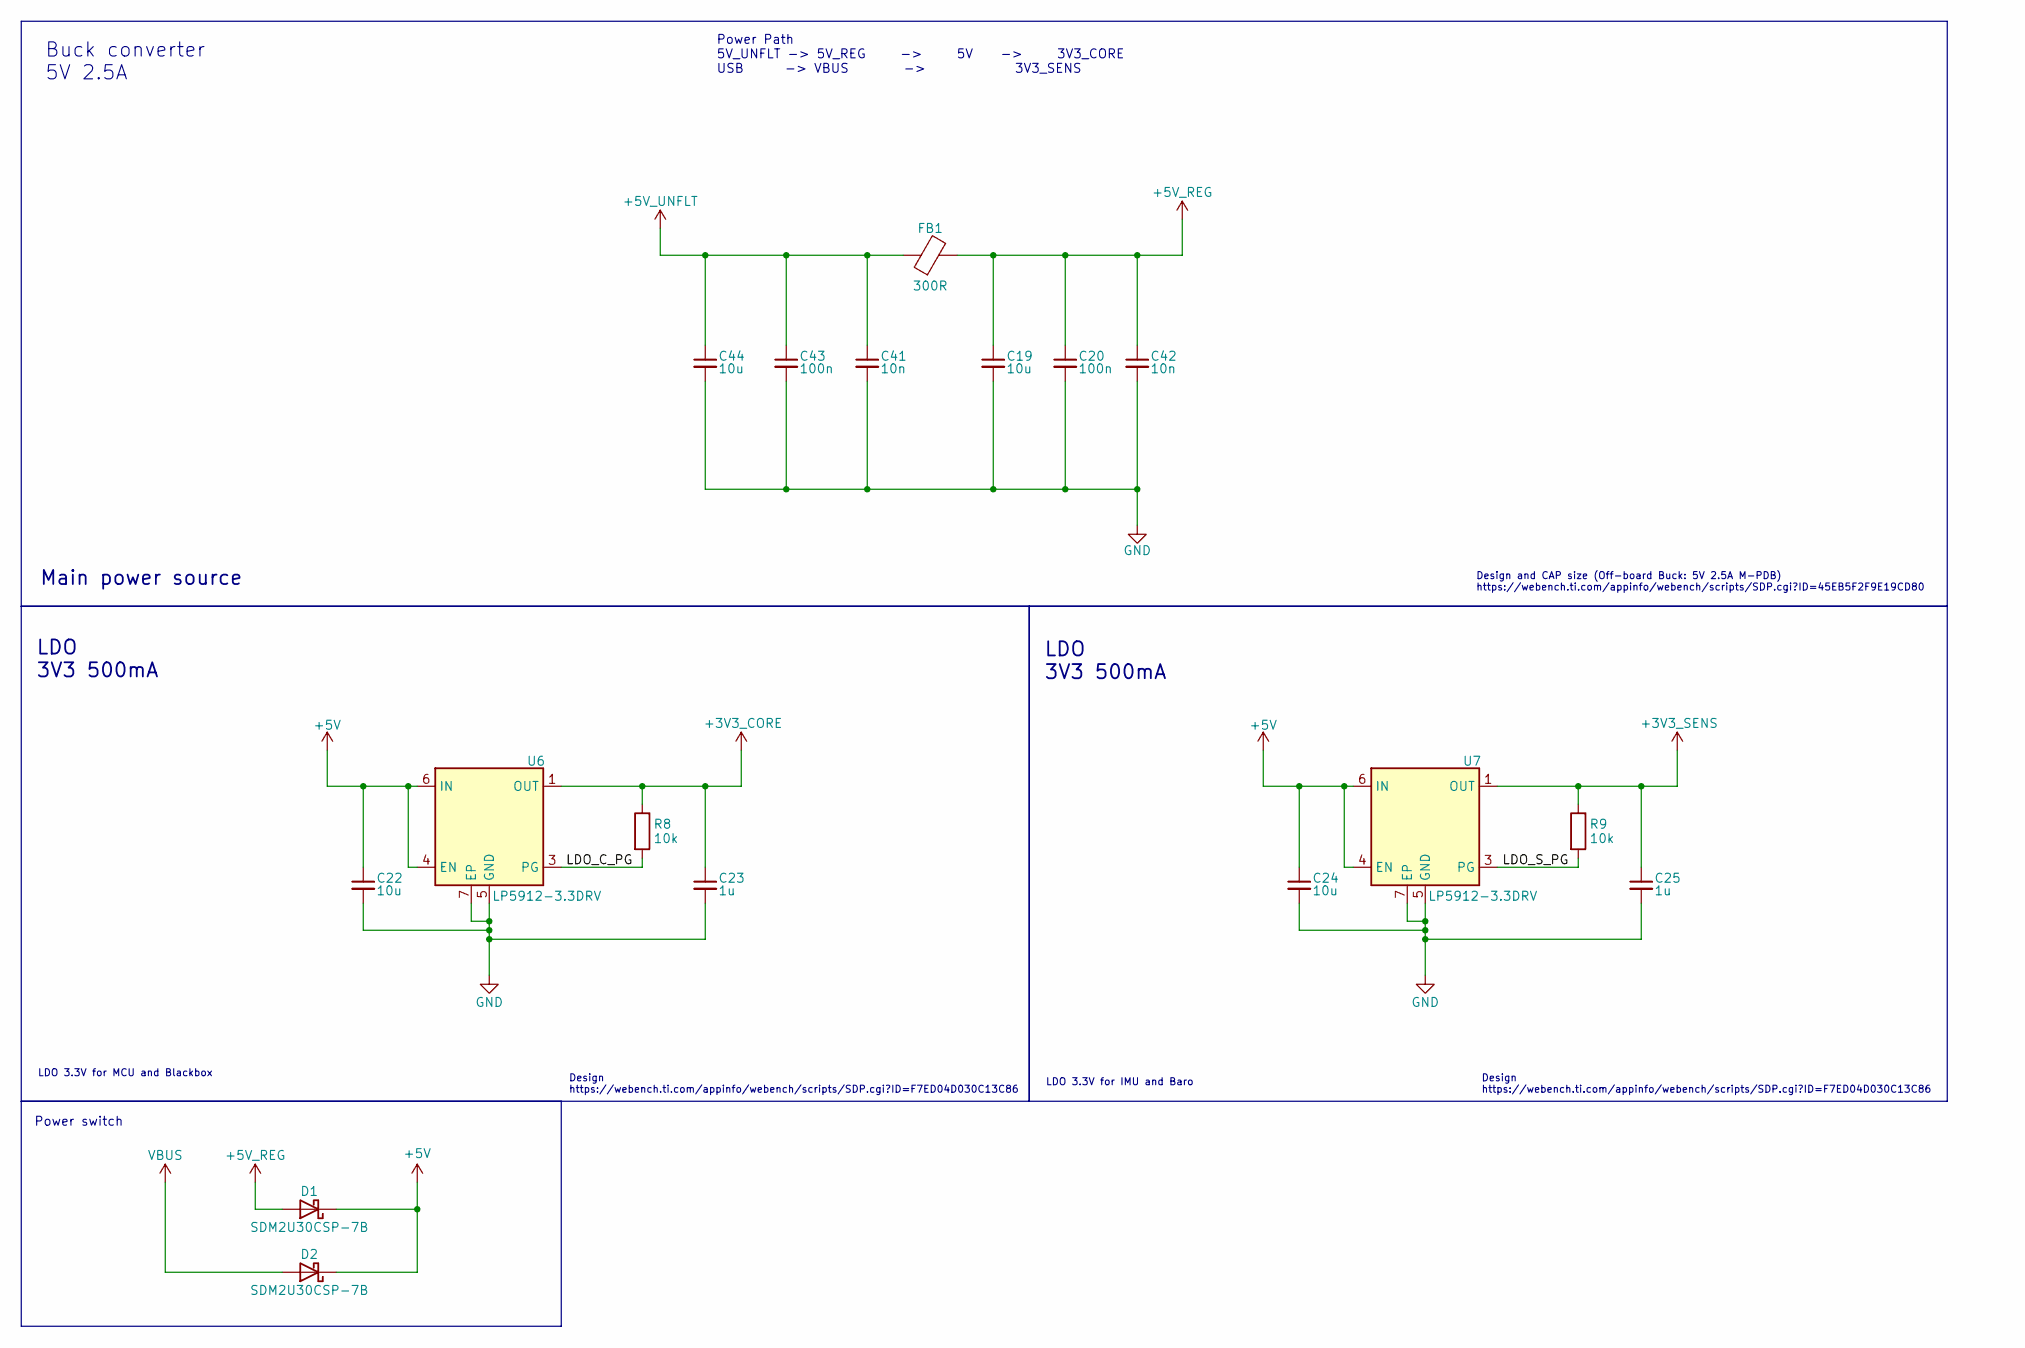
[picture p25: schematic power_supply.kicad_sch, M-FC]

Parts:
C19, C22, C24, C44: 10u; C_0402_1005Metric
C20, C43: 100n; C_0402_1005Metric
C23, C25: 1u; C_0402_1005Metric
C41, C42: 10n; C_0402_1005Metric
D1, D2: SDM2U30CSP-7B; DIO_SDM2U40CSP-7B
FB1: 300R; C_0805_2012Metric
R8, R9: 10k; R_0402_1005Metric
U6, U7: LP5912-3.3DRV; SON65P200X200X80-7N

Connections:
+3V3_CORE: C23.1, R8.1, U6.1 (OUT); also elsewhere on the board
+3V3_SENS: C25.1, R9.1, U7.1 (OUT); also elsewhere on the board
+5V: C22.1, C24.1, D1.1 (K), D2.1 (K), U6.4 (EN), U6.6 (IN), U7.4 (EN), U7.6 (IN); also elsewhere on the board
+5V_REG: C19.1, C20.1, C42.1, D1.2 (A), FB1.2; also elsewhere on the board
+5V_UNFLT: C41.1, C43.1, C44.1, FB1.1; also elsewhere on the board
/Power supply/LDO_C_PG: R8.2, U6.3 (PG)
/Power supply/LDO_S_PG: R9.2, U7.3 (PG)
GND: C19.2, C20.2, C22.2, C23.2, C24.2, C25.2, C41.2, C42.2, C43.2, C44.2, U6.5 (GND), U6.7 (EP), U7.5 (GND), U7.7 (EP); also elsewhere on the board
VBUS: D2.2 (A); also elsewhere on the board

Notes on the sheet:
Design https://webench.ti.com/appinfo/webench/scripts/SDP.cgi?ID=F7ED04D030C13C86
Power Path 5V_UNFLT -> 5V_REG -> 5V -> 3V3_CORE USB -> VBUS -> 3V3_SENS
Buck converter 5V 2.5A
Design and CAP size (Off-board Buck: 5V 2.5A M-PDB) https://webench.ti.com/appinfo/webench/scripts/SDP.cgi?ID=45EB5F2F9E19CD80
Main power source
LDO 3V3 500mA
Power switch
LDO 3.3V for MCU and Blackbox
LDO 3.3V for IMU and Baro

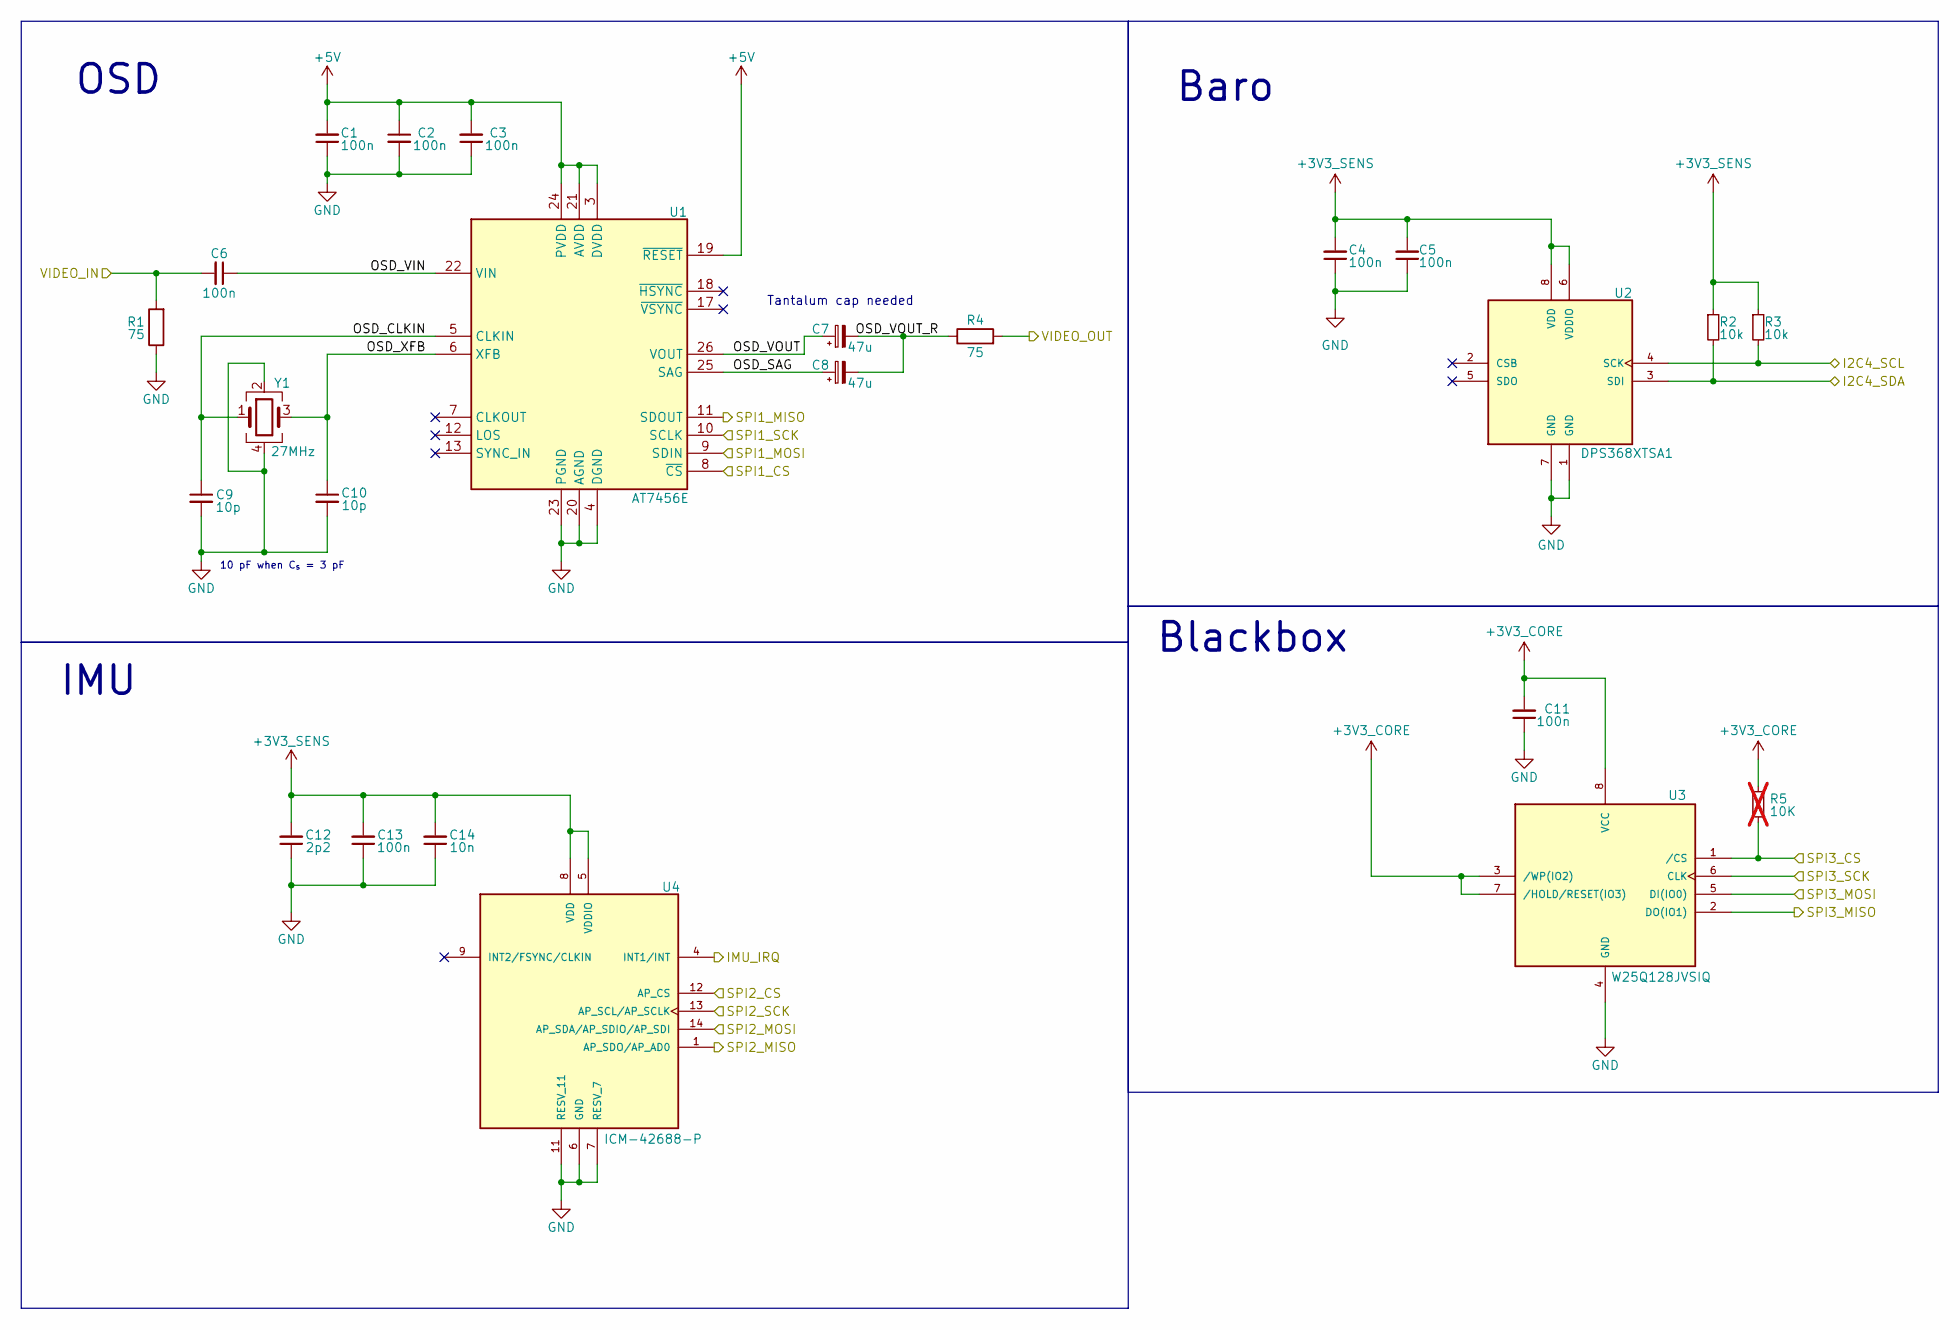
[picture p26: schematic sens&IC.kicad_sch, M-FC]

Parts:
C1, C2, C3, C4, C5, C6, C11, C13: 100n; C_0402_1005Metric
C7, C8: 47u; C_1206_3216Metric
C9, C10: 10p; C_0402_1005Metric
C12: 2p2; C_0402_1005Metric
C14: 10n; C_0402_1005Metric
R1, R4: 75; R_0402_1005Metric
R2, R3: 10k; R_0402_1005Metric
R5: 10K; R_0402_1005Metric; not fitted
U1: AT7456E; TSSOP-28_L9.7-W4.4-P0.65-LS6.4-BL-EP-2; Manufacturer_Part_Number AT7456E
U2: DPS368XTSA1; XDCR_DPS368XTSA1; DigiKey_Part_Number DPS368XTSA1TR-ND
U3: W25Q128JVSIQ; SOIC127P790X216-8N; PARTREV I
U4: ICM-42688-P; PQFN50P300X250X97-14N; PARTREV 1.2
Y1: 27MHz; CRYSTAL-SMD_4P-L2.0-W1.6-BL

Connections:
+3V3_CORE: C11.2, R5.1, U3.3 (/WP(IO2)), U3.7 (/HOLD/RESET(IO3)), U3.8 (VCC); also elsewhere on the board
+3V3_SENS: C4.2, C5.2, C12.2, C13.2, C14.2, R2.1, R3.1, U2.6 (VDDIO), U2.8 (VDD), U4.5 (VDDIO), U4.8 (VDD); also elsewhere on the board
+5V: C1.2, C2.1, C3.2, U1.3 (DVDD), U1.19 (~RESET), U1.21 (AVDD), U1.24 (PVDD); also elsewhere on the board
/Connectors/VIDEO_IN: C6.2, R1.2; also elsewhere on the board
/Connectors/VIDEO_OUT: R4.2; also elsewhere on the board
/MCU/I2C4_SCL: R3.2, U2.4 (SCK); also elsewhere on the board
/MCU/I2C4_SDA: R2.2, U2.3 (SDI); also elsewhere on the board
/MCU/IMU_IRQ: U4.4 (INT1/INT); also elsewhere on the board
/MCU/SPI1_CS: U1.8 (~CS); also elsewhere on the board
/MCU/SPI1_MISO: U1.11 (SDOUT); also elsewhere on the board
/MCU/SPI1_MOSI: U1.9 (SDIN); also elsewhere on the board
/MCU/SPI1_SCK: U1.10 (SCLK); also elsewhere on the board
/MCU/SPI2_CS: U4.12 (AP_CS); also elsewhere on the board
/MCU/SPI2_MISO: U4.1 (AP_SDO/AP_AD0); also elsewhere on the board
/MCU/SPI2_MOSI: U4.14 (AP_SDA/AP_SDIO/AP_SDI); also elsewhere on the board
/MCU/SPI2_SCK: U4.13 (AP_SCL/AP_SCLK); also elsewhere on the board
/MCU/SPI3_CS: R5.2, U3.1 (/CS); also elsewhere on the board
/MCU/SPI3_MISO: U3.2 (DO(IO1)); also elsewhere on the board
/MCU/SPI3_MOSI: U3.5 (DI(IO0)); also elsewhere on the board
/MCU/SPI3_SCK: U3.6 (CLK); also elsewhere on the board
/Sensors & IC/OSD_CLKIN: C9.1, U1.5 (CLKIN), Y1.1
/Sensors & IC/OSD_SAG: C8.1, U1.25 (SAG)
/Sensors & IC/OSD_VIN: C6.1, U1.22 (VIN)
/Sensors & IC/OSD_VOUT: C7.1, U1.26 (VOUT)
/Sensors & IC/OSD_VOUT_R: C7.2, C8.2, R4.1
/Sensors & IC/OSD_XFB: C10.1, U1.6 (XFB), Y1.3
GND: C1.1, C2.2, C3.1, C4.1, C5.1, C9.2, C10.2, C11.1, C12.1, C13.1, C14.1, R1.1, U1.4 (DGND), U1.20 (AGND), U1.23 (PGND), U2.1 (GND), U2.7 (GND), U3.4 (GND), U4.6 (GND), U4.7 (RESV_7), U4.11 (RESV_11), Y1.2, Y1.4; also elsewhere on the board

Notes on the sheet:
IMU
10 pF when C_{s} = 3 pF
Blackbox
OSD
Tantalum cap needed
Baro

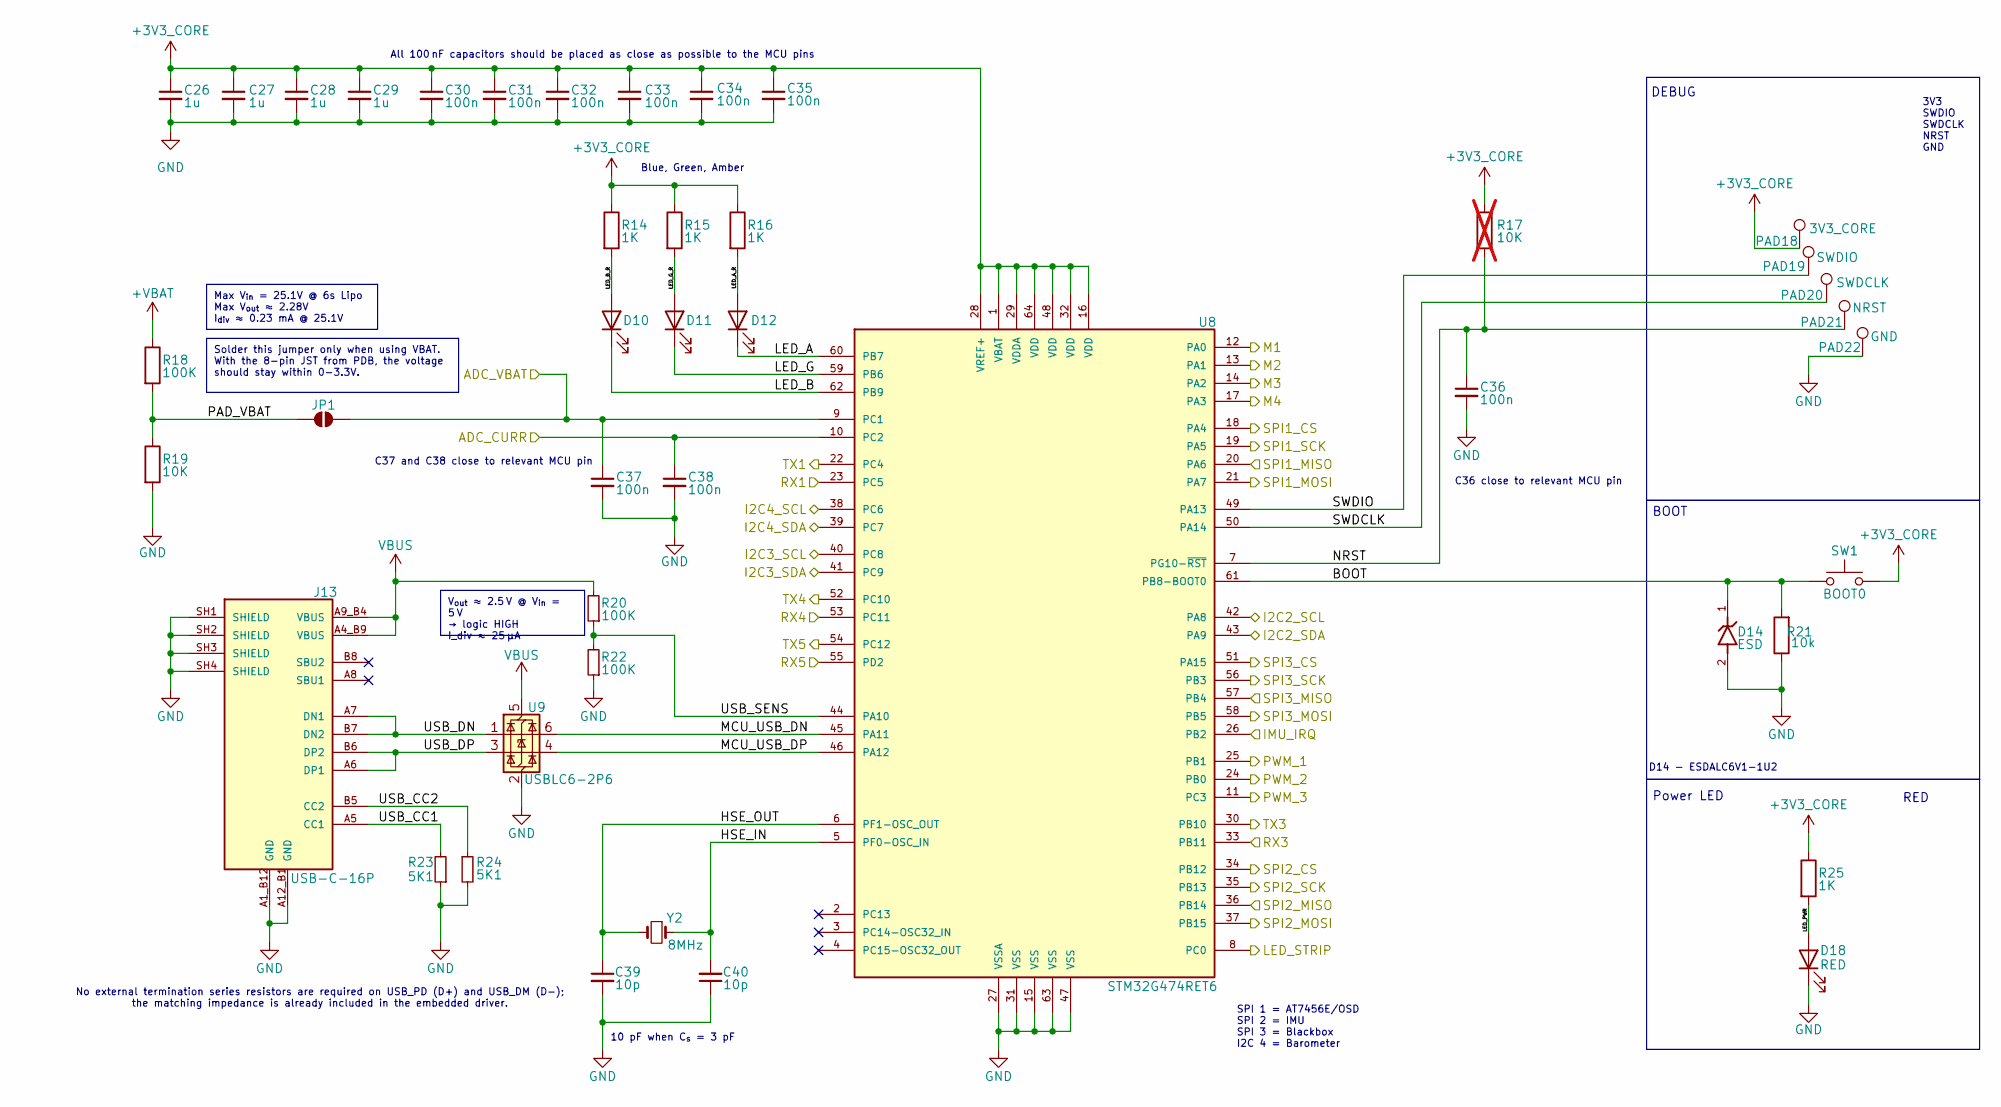
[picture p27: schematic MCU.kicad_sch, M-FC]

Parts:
C26, C27, C28, C29: 1u; C_0402_1005Metric
C30, C31, C32, C33, C34, C35, C36, C37, C38: 100n; C_0402_1005Metric
C39, C40: 10p; C_0402_1005Metric
D10: Blue; LED_0603_1608Metric
D11: Green; LED_0603_1608Metric
D12: Amber; LED_0603_1608Metric
D14: ESD; ESDALC6V1-1U2; PARTREV 3
D18: RED; LED_0603_1608Metric
J13: USB-C-16P; KINGHELM_KH-TYPE-C-16P; PARTREV A0
JP1: SolderJumper_2_Open; C_0402_1005Metric
PAD18: 3V3_CORE; TestPoint_Pad_D1.0mm
PAD19: SWDIO; TestPoint_Pad_D1.0mm
PAD20: SWDCLK; TestPoint_Pad_D1.0mm
PAD21: NRST; TestPoint_Pad_D1.0mm
PAD22: GND; TestPoint_Pad_D1.0mm
R14, R15, R16, R25: 1K; R_0402_1005Metric
R17: 10K; R_0402_1005Metric; not fitted
R18, R20, R22: 100K; R_0402_1005Metric
R19: 10K; R_0402_1005Metric
R21: 10k; R_0402_1005Metric
R23, R24: 5K1; R_0402_1005Metric
SW1: BOOT0; SW_B3U-1000P
U8: STM32G474RET6; QFP50P1200X1200X160-64N; PARTREV 6
U9: USBLC6-2P6; SOT50P160X60-6N
Y2: 8MHz; XTAL_NX3225GD-8MHZ-STD-CRA-3

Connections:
+3V3_CORE: C26.1, C27.1, C28.1, C29.1, C30.1, C31.1, C32.1, C33.1, C34.1, C35.1, PAD18.1, R14.1, R15.1, R16.1, R17.1, R25.1, SW1.2, U8.1 (VBAT), U8.16 (VDD), U8.28 (VREF+), U8.29 (VDDA), U8.32 (VDD), U8.48 (VDD), U8.64 (VDD); also elsewhere on the board
+VBAT: R18.1; also elsewhere on the board
/Connectors/ADC_CURR: C38.1, U8.10 (PC2); also elsewhere on the board
/Connectors/ADC_VBAT: C37.1, JP1.2 (B), U8.9 (PC1); also elsewhere on the board
/Connectors/I2C2_SCL: U8.42 (PA8); also elsewhere on the board
/Connectors/I2C2_SDA: U8.43 (PA9); also elsewhere on the board
/Connectors/I2C3_SCL: U8.40 (PC8); also elsewhere on the board
/Connectors/I2C3_SDA: U8.41 (PC9); also elsewhere on the board
/Connectors/LED_STRIP: U8.8 (PC0); also elsewhere on the board
/Connectors/M1: U8.12 (PA0); also elsewhere on the board
/Connectors/M2: U8.13 (PA1); also elsewhere on the board
/Connectors/M3: U8.14 (PA2); also elsewhere on the board
/Connectors/M4: U8.17 (PA3); also elsewhere on the board
/Connectors/PWM_1: U8.25 (PB1); also elsewhere on the board
/Connectors/PWM_2: U8.24 (PB0); also elsewhere on the board
/Connectors/PWM_3: U8.11 (PC3); also elsewhere on the board
/Connectors/RX1: U8.23 (PC5); also elsewhere on the board
/Connectors/RX3: U8.33 (PB11); also elsewhere on the board
/Connectors/RX4: U8.53 (PC11); also elsewhere on the board
/Connectors/RX5: U8.55 (PD2); also elsewhere on the board
/Connectors/TX1: U8.22 (PC4); also elsewhere on the board
/Connectors/TX3: U8.30 (PB10); also elsewhere on the board
/Connectors/TX4: U8.52 (PC10); also elsewhere on the board
/Connectors/TX5: U8.54 (PC12); also elsewhere on the board
/MCU/BOOT: D14.1, R21.2, SW1.1, U8.61 (PB8-BOOT0)
/MCU/HSE_IN: C40.2, U8.5 (PF0-OSC_IN), Y2.1
/MCU/HSE_OUT: C39.1, U8.6 (PF1-OSC_OUT), Y2.2
/MCU/I2C4_SCL: U8.38 (PC6); also elsewhere on the board
/MCU/I2C4_SDA: U8.39 (PC7); also elsewhere on the board
/MCU/IMU_IRQ: U8.26 (PB2); also elsewhere on the board
/MCU/LED_A: D12.1 (K), U8.60 (PB7)
/MCU/LED_A_R: D12.2 (A), R16.2
/MCU/LED_B: D10.1 (K), U8.62 (PB9)
/MCU/LED_B_R: D10.2 (A), R14.2
/MCU/LED_G: D11.1 (K), U8.59 (PB6)
/MCU/LED_G_R: D11.2 (A), R15.2
/MCU/LED_PWR: D18.2 (A), R25.2
/MCU/MCU_USB_DN: U8.45 (PA11), U9.6 (I/O1)
/MCU/MCU_USB_DP: U8.46 (PA12), U9.4 (I/O2)
/MCU/NRST: C36.1, PAD21.1, R17.2, U8.7 (PG10-~RST)
/MCU/PAD_VBAT: JP1.1 (A), R18.2, R19.1
/MCU/SPI1_CS: U8.18 (PA4); also elsewhere on the board
/MCU/SPI1_MISO: U8.20 (PA6); also elsewhere on the board
/MCU/SPI1_MOSI: U8.21 (PA7); also elsewhere on the board
/MCU/SPI1_SCK: U8.19 (PA5); also elsewhere on the board
/MCU/SPI2_CS: U8.34 (PB12); also elsewhere on the board
/MCU/SPI2_MISO: U8.36 (PB14); also elsewhere on the board
/MCU/SPI2_MOSI: U8.37 (PB15); also elsewhere on the board
/MCU/SPI2_SCK: U8.35 (PB13); also elsewhere on the board
/MCU/SPI3_CS: U8.51 (PA15); also elsewhere on the board
/MCU/SPI3_MISO: U8.57 (PB4); also elsewhere on the board
/MCU/SPI3_MOSI: U8.58 (PB5); also elsewhere on the board
/MCU/SPI3_SCK: U8.56 (PB3); also elsewhere on the board
/MCU/SWDCLK: PAD20.1, U8.50 (PA14)
/MCU/SWDIO: PAD19.1, U8.49 (PA13)
/MCU/USB_CC1: J13.A5 (CC1), R23.2
/MCU/USB_CC2: J13.B5 (CC2), R24.1
/MCU/USB_DN: J13.A7 (DN1), J13.B7 (DN2), U9.1 (I/O1)
/MCU/USB_DP: J13.A6 (DP1), J13.B6 (DP2), U9.3 (I/O2)
/MCU/USB_SENS: R20.1, R22.2, U8.44 (PA10)
GND: C26.2, C27.2, C28.2, C29.2, C30.2, C31.2, C32.2, C33.2, C34.2, C35.2, C36.2, C37.2, C38.2, C39.2, C40.1, D14.2, D18.1 (K), J13.A1_B12 (GND), J13.A12_B1 (GND), J13.SH1 (SHIELD), J13.SH2 (SHIELD), J13.SH3 (SHIELD), J13.SH4 (SHIELD), PAD22.1, R19.2, R21.1, R22.1, R23.1, R24.2, U8.15 (VSS), U8.27 (VSSA), U8.31 (VSS), U8.47 (VSS), U8.63 (VSS), U9.2 (GND); also elsewhere on the board
VBUS: J13.A4_B9 (VBUS), J13.A9_B4 (VBUS), R20.2, U9.5 (VBUS); also elsewhere on the board

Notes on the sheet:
10 pF when C_{s} = 3 pF
No external termination series resistors are required on USB_PD (D+) and USB_DM (D-); the matching impedance is already included in the embedded driver.
Power LED
C37 and C38 close to relevant MCU pin
All 100 nF capacitors should be placed as close as possible to the MCU pins
3V3 SWDIO SWDCLK NRST GND
DEBUG
SPI 1 = AT7456E/OSD SPI 2 = IMU SPI 3 = Blackbox I2C 4 = Barometer
C36 close to relevant MCU pin
D14 - ESDALC6V1-1U2
BOOT
RED
Blue, Green, Amber
Max V_{in} = 25.1V @ 6s Lipo Max V_{out} ≈ 2.28V I_{div} ≈ 0.23 mA @ 25.1V
Solder this jumper only when using VBAT. With the 8-pin JST from PDB, the voltage should stay within 0-3.3V.
V_{out} ≈ 2.5 V @ V_{in} = 5 V → logic HIGH I_div ≈ 25 µA

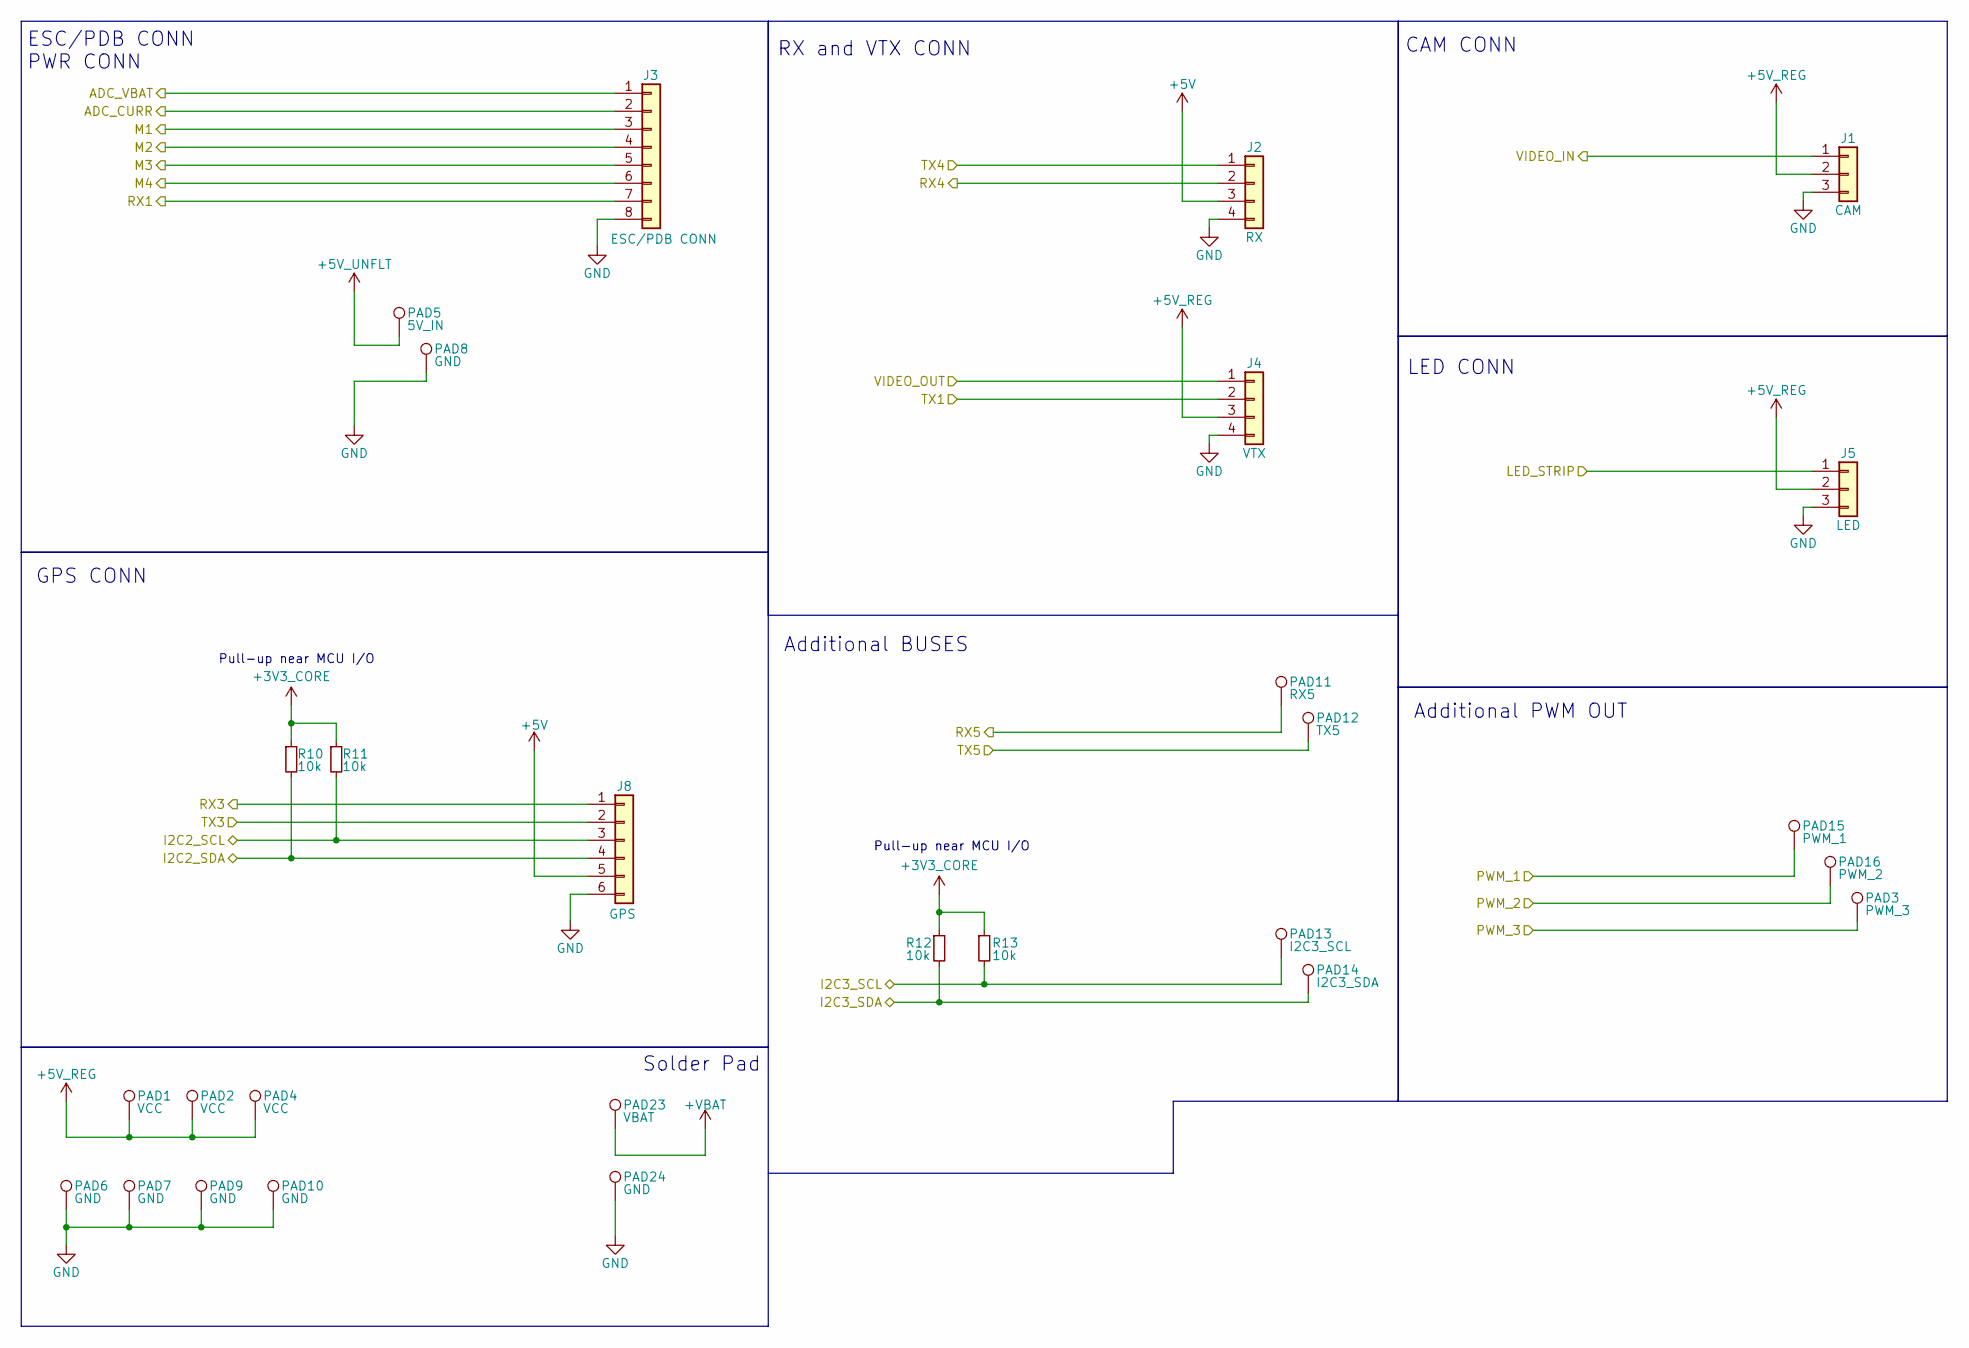
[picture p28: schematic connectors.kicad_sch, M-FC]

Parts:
J1: CAM; JST_SH_SM03B-SRSS-TB_03x1.00mm_Angled
J2: RX; JST_SH_SM04B-SRSS-TB_04x1.00mm_Angled
J3: ESC/PDB CONN; JST_SH_SM08B-SRSS-TB_08x1.00mm_Angled
J4: VTX; JST_SH_SM04B-SRSS-TB_04x1.00mm_Angled
J5: LED; JST_SH_SM03B-SRSS-TB_03x1.00mm_Angled
J8: GPS; CONN-SMD_6P-P1.00_XUNPU_WAFER-SH1.0-6PWB
PAD1, PAD2, PAD4: VCC; TestPoint_Pad_1.5x1.5mm
PAD3: PWM_3; TestPoint_Pad_1.5x1.5mm
PAD5: 5V_IN; TestPoint_Pad_1.5x1.5mm
PAD6, PAD7, PAD8, PAD9, PAD10: GND; TestPoint_Pad_1.5x1.5mm
PAD11: RX5; TestPoint_Pad_1.5x1.5mm
PAD12: TX5; TestPoint_Pad_1.5x1.5mm
PAD13: I2C3_SCL; TestPoint_Pad_1.5x1.5mm
PAD14: I2C3_SDA; TestPoint_Pad_1.5x1.5mm
PAD15: PWM_1; TestPoint_Pad_1.5x1.5mm
PAD16: PWM_2; TestPoint_Pad_1.5x1.5mm
PAD23: VBAT; TestPoint_Pad_1.0x1.0mm
PAD24: GND; TestPoint_Pad_1.0x1.0mm
R10, R11, R12, R13: 10k; R_0402_1005Metric

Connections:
+3V3_CORE: R10.1, R11.1, R12.1, R13.1; also elsewhere on the board
+5V: J2.3, J8.5; also elsewhere on the board
+5V_REG: J1.2, J4.3, J5.2, PAD1.1, PAD2.1, PAD4.1; also elsewhere on the board
+5V_UNFLT: PAD5.1; also elsewhere on the board
+VBAT: PAD23.1; also elsewhere on the board
/Connectors/ADC_CURR: J3.2; also elsewhere on the board
/Connectors/ADC_VBAT: J3.1; also elsewhere on the board
/Connectors/I2C2_SCL: J8.3, R11.2; also elsewhere on the board
/Connectors/I2C2_SDA: J8.4, R10.2; also elsewhere on the board
/Connectors/I2C3_SCL: PAD13.1, R13.2; also elsewhere on the board
/Connectors/I2C3_SDA: PAD14.1, R12.2; also elsewhere on the board
/Connectors/LED_STRIP: J5.1; also elsewhere on the board
/Connectors/M1: J3.3; also elsewhere on the board
/Connectors/M2: J3.4; also elsewhere on the board
/Connectors/M3: J3.5; also elsewhere on the board
/Connectors/M4: J3.6; also elsewhere on the board
/Connectors/PWM_1: PAD15.1; also elsewhere on the board
/Connectors/PWM_2: PAD16.1; also elsewhere on the board
/Connectors/PWM_3: PAD3.1; also elsewhere on the board
/Connectors/RX1: J3.7; also elsewhere on the board
/Connectors/RX3: J8.1; also elsewhere on the board
/Connectors/RX4: J2.2; also elsewhere on the board
/Connectors/RX5: PAD11.1; also elsewhere on the board
/Connectors/TX1: J4.2; also elsewhere on the board
/Connectors/TX3: J8.2; also elsewhere on the board
/Connectors/TX4: J2.1; also elsewhere on the board
/Connectors/TX5: PAD12.1; also elsewhere on the board
/Connectors/VIDEO_IN: J1.1; also elsewhere on the board
/Connectors/VIDEO_OUT: J4.1; also elsewhere on the board
GND: J1.3, J2.4, J3.8, J4.4, J5.3, J8.6, PAD6.1, PAD7.1, PAD8.1, PAD9.1, PAD10.1, PAD24.1; also elsewhere on the board

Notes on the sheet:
CAM CONN
GPS CONN
Additional PWM OUT
ESC/PDB CONN PWR CONN
LED CONN
Additional BUSES
Pull-up near MCU I/O
RX and VTX CONN
Solder Pad

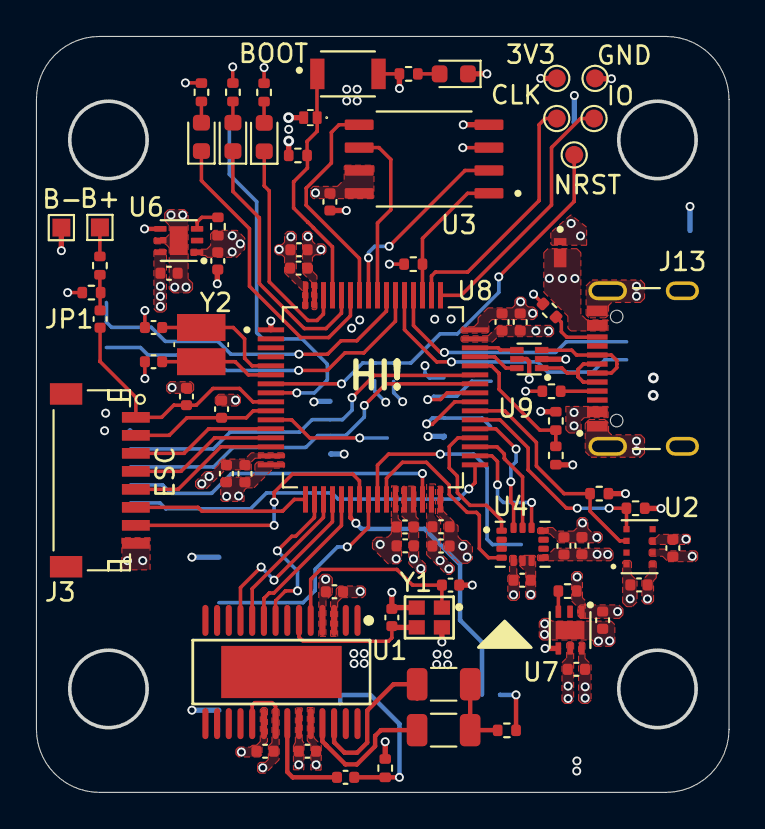
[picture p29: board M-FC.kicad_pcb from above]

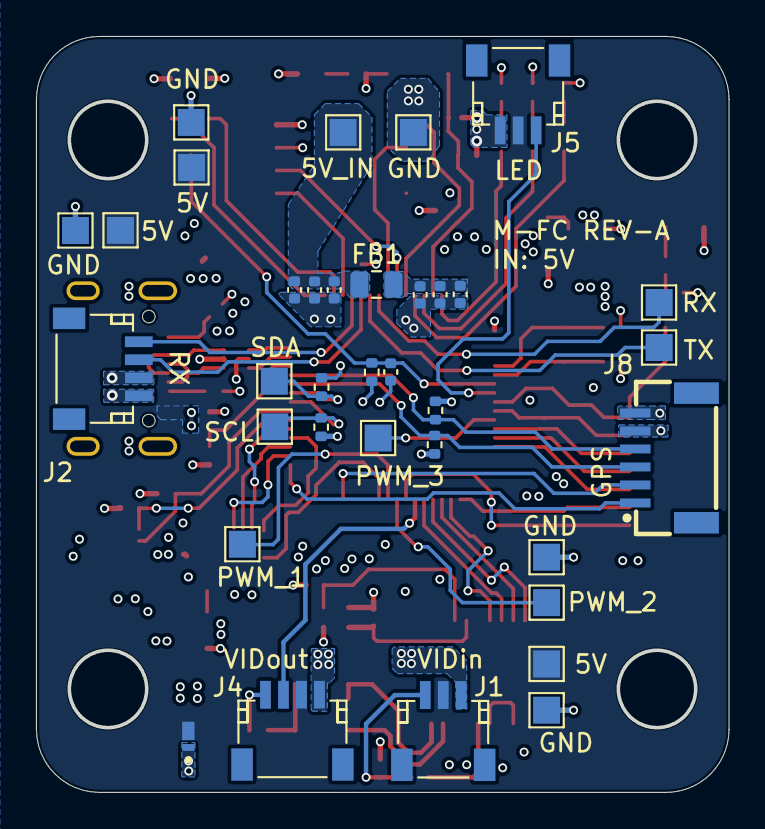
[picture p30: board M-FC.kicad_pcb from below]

Board: 4 copper layers, 38.5 x 42.0 mm, 112 parts (35 on the bottom side), 76 nets.

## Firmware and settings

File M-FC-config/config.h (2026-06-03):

/*
 * This file is part of Betaflight.
 *
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
 * See the GNU General Public License for more details.
 *
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
 * If not, see <http://www.gnu.org/licenses/>.
 
 It's for testing purpose for new Open source FC
 */

#pragma once

#define FC_TARGET_MCU     STM32G47X

#define BOARD_NAME        M-FC
#define MANUFACTURER_ID   Cust


 //IMU
#define USE_ACC
#define USE_ACC_SPI_ICM42688P
#define USE_GYRO
#define USE_GYRO_SPI_ICM42688P

#define GYRO_1_EXTI_PIN                 PB2
#define USE_GYRO_EXTI
#define GYRO_1_CS_PIN                   PB12
#define SPI2_SCK_PIN                    PB13
#define SPI2_SDI_PIN                    PB14
#define SPI2_SDO_PIN                    PB15

#define GYRO_1_SPI_INSTANCE             SPI2

#define GYRO_1_ALIGN                    CW90_DEG

 //BARO
#define USE_BARO
#define USE_BARO_DPS310

#define I2C4_SCL_PIN                    PC6
#define I2C4_SDA_PIN                    PC7

#define BARO_I2C_INSTANCE               I2CDEV_4
#define DEFAULT_BARO_I2C_ADDRESS        119

 //FLASH
#define USE_FLASH
#define USE_FLASH_W25Q128FV

#define FLASH_CS_PIN                    PA15
#define SPI3_SCK_PIN                    PB3
#define SPI3_SDI_PIN                    PB4
#define SPI3_SDO_PIN                    PB5

#define FLASH_SPI_INSTANCE              SPI3

#define DEFAULT_BLACKBOX_DEVICE         BLACKBOX_DEVICE_FLASH


 //OSD
#define USE_MAX7456

#define MAX7456_SPI_CS_PIN   			PA4
#define SPI1_SCK_PIN                    PA5
#define SPI1_SDI_PIN                    PA6
#define SPI1_SDO_PIN                    PA7

#define MAX7456_SPI_INSTANCE SPI1

 //USB
#define USB_DETECT_PIN       PA10

 //MOTOR & PWM
#define MOTOR1_PIN           PA0
#define MOTOR2_PIN           PA1
#define MOTOR3_PIN           PA2
#define MOTOR4_PIN           PA3


#define USE_DSHOT
#define DEFAULT_DSHOT_BITBANG DSHOT_BITBANG_ON

 //LED STRIP 
#define USE_LED_STRIP
#define LED_STRIP_PIN        PC0

 //Buzzer
#define BEEPER_PIN           PC3  
#define BEEPER_INVERTED

 //DEBUG LED
#define LED0_PIN             PB7
#define LED1_PIN             PB6
#define LED2_PIN             PB9

 //ADC
#define ADC_VBAT_PIN         PC1
#define ADC_CURR_PIN         PC2

#define DEFAULT_VOLTAGE_METER_SOURCE    VOLTAGE_METER_ADC
#define DEFAULT_VOLTAGE_METER_SCALE     110

#define ADC1_DMA_OPT        1

 //ADDITIONAL RESOURCES
#define UART1_TX_PIN         PC4
#define UART1_RX_PIN         PC5

#define UART3_TX_PIN         PB10
#define UART3_RX_PIN         PB11

#define UART4_TX_PIN         PC10
#define UART4_RX_PIN         PC11

#define UART5_TX_PIN         PC12
#define UART5_RX_PIN         PD2

#define I2C2_SCL_PIN         PA8
#define I2C2_SDA_PIN         PA9

#define I2C3_SCL_PIN         PC8
#define I2C3_SDA_PIN         PC9

 //GPS
#define USE_GPS
 
 //MAG
#define USE_MAG
#define MAG_I2C_INSTANCE I2CDEV_2
 
 //Camera Control
#define USE_CAMERA_CONTROL
#define CAMERA_CONTROL_PIN PB0

 
 //POSITION HOLD & ALTITUDE
#define USE_POSITION_HOLD
#define USE_ALTITUDE_HOLD
 
 
 //TIMER MAP
#define TIMER_PIN_MAPPING \
	TIMER_PIN_MAP( 0, MOTOR1_PIN , 2,  1) \
    TIMER_PIN_MAP( 1, MOTOR2_PIN , 2,  2) \
    TIMER_PIN_MAP( 2, MOTOR3_PIN , 2,  3) \
    TIMER_PIN_MAP( 3, MOTOR4_PIN , 2,  4) \
    TIMER_PIN_MAP( 4, CAMERA_CONTROL_PIN , 3,  3) \
	TIMER_PIN_MAP( 5, LED_STRIP_PIN , 1,  1) 

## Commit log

2026-05-15 Create .gitignore for KiCad project
    Add .gitignore for KiCad project files and temporary files
2026-05-15 Revise README for Modular Flight Controller REV-1
    Updated README to reflect changes for REV-1, including detailed specifications, power architecture, and known issues.
2026-05-20 Add mounting hole dimensions to overview
    Updated the overview section to include mounting hole dimensions.

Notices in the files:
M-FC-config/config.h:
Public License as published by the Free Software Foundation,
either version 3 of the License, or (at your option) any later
